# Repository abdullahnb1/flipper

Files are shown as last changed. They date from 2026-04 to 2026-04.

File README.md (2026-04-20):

# Final Engineering Design Project

Project Animation

## Project Overview
This repository contains the CAD assemblies and electronic specifications for the final design project of **ME461: Mechatronic Components and Instrumentation**. The system is designed with a focus on modularity and ease of assembly, utilizing standardized fasteners and common manufacturing techniques.

It is collaboratively maintained by:

- **Abdullah Naci Bodur**  
- **Ogan Altuğ Okutan**  
- **Buğra Çınaroğlu**

## Folder Structure
```
├── base/
│   ├── 3d/                     # 3d parts for base assembly
│   ├── BOM of base_assembly.csv
│   ├── BOM of base_electronic_assembly.csv
│   ├── BOM of base_rasppi_assembly.csv
│   ├── BOM of battery_base_assembly.csv
│   └── BOM of pico_base_assembly.csv
├── flipper/
│   ├── 3d/                     # 3d parts for flipper assembly
│   ├── plexy/                  # plexy parts for flipper assembly   
|   └── BOM of flipper_v2_assembly.csv       
└── media/                      # Assembly and manufacturing images
└── pc_client_code/             # MicroPython code for Pico W
```   

## Manufacturing Specifications
* **3D Printing:** Primary structural components are printed using **PLA**.
* **Laser Cutting:** Support plates and enclosures are manufactured from **Plexiglass**.
* **Fasteners:** For maintenance convenience and standardization, the entire assembly utilizes **M3 Hex Socket Screws** exclusively.

---

## CAD Design & Assembly

### 1. Robot Base
The primary chassis of the robot, housing the 18650 battery pack, 4S BMS, and power regulation systems. This section serves as the structural foundation for the entire assembly.

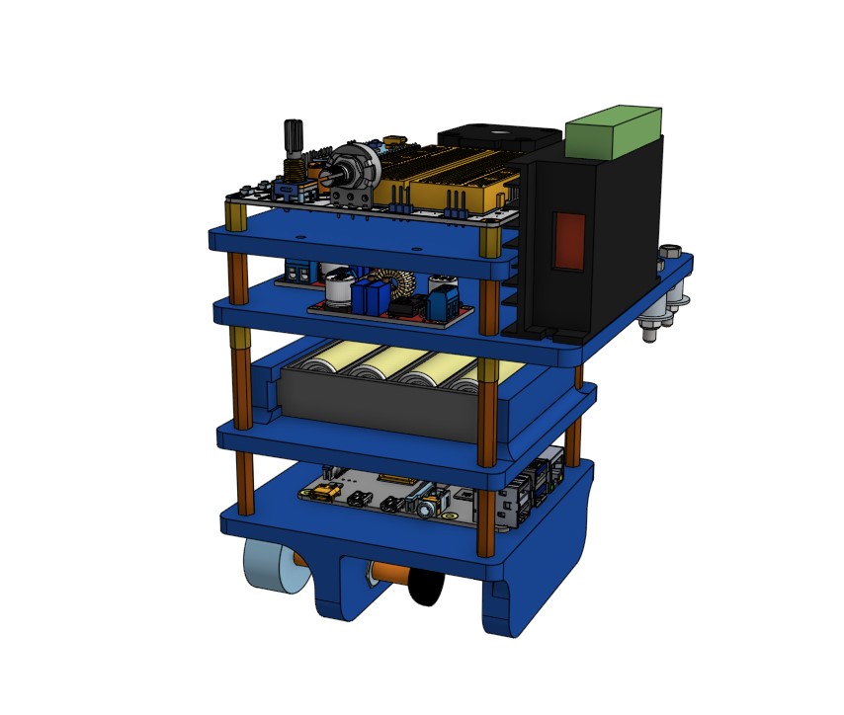
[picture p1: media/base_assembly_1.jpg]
Robot Base

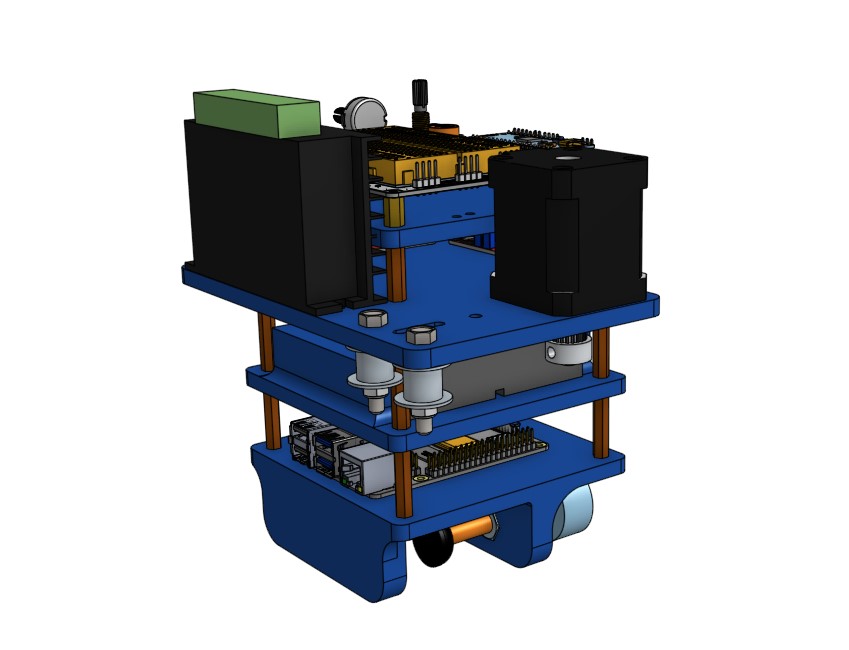
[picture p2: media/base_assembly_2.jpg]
Robot Base


### 2. Flipper Mechanism
The active actuation system of the robot. This folder contains the designs for the rolling carts mounts, the MG90S servo integration, and the mechanical linkages responsible for the flipping motion.

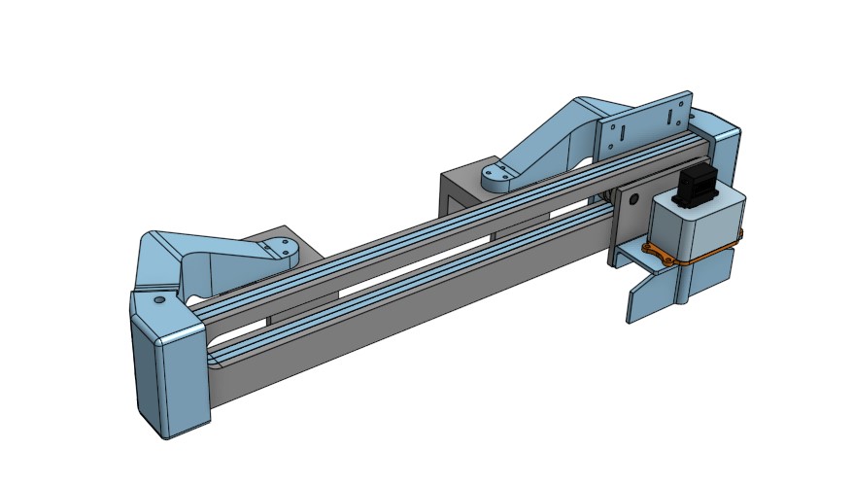
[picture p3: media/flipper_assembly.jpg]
Flipper Mechanism


### 3. Table Assembly
The stationary or receiving platform of the design. It incorporates the aluminum extruision parts that shows the game area, and a table that is inclined 5-8 degree relative to ground. Also 2 version of the **Flipper Robot** is shown; on the left v1 and on the right v2. Only the version 2 files added to the repository.

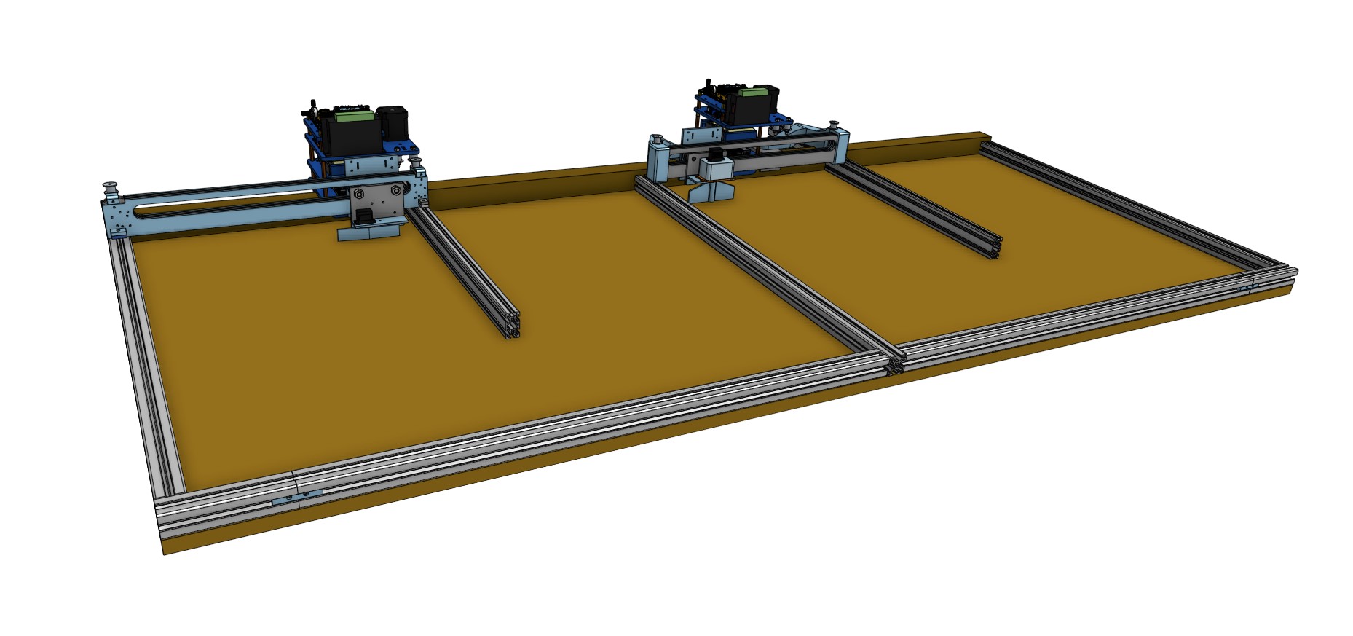
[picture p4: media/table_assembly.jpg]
Table Assembly


---

## Electronics
The system is powered by a high-discharge battery configuration and controlled via a Raspberry Pi Pico W architecture.

| Component | Quantity | Description |
| :--- | :--- | :--- |
| **Raspberry Pi Pico W** | 1 | Main microcontroller for logic and wireless connectivity. |
| **MechaBoard** | 1 | Integrated carrier board. [View on GitHub](https://github.com/rustemsevik/pico-Breadboard-Kit/tree/5a5b2b6fdedf8019d1d9c465f88ec24519eb11b5) |
| **18650 Li-ion Cells** | 4 | Primary power source (4S configuration). |
| **4S BMS** | 1 | Battery Management System for charging and protection. |
| **XL 4015** | 2 | Adjustable step-down voltage regulators for logic and motors. |
| **Nema17 Stepper** | 1 | High-torque motor for primary actuation. |
| **Microstepper Driver** | 1 | Controls the Nema17 with high microstepping resolution. |
| **MG90S Servo** | 1 | Metal-geared micro servo for auxiliary movement. |
| **Limit Switch** | 2 | Used for homing and physical end-stop detection. |

---

## Assembly Quick-Start
1.  **Fabrication:** Print PLA parts and laser cut Plexiglass components.
2.  **Hardware:** Gather M3 hex socket screws for all mechanical connections.
3.  **Electronics:** Mount the Pico W onto the MechaBoard and configure the XL 4015 regulators to the required voltages before connecting logic components.
4.  **Firmware:** Upload the control script to the Pico W.

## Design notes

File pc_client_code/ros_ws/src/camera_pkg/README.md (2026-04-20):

To run this package you first need to create a ROS2 Humble workspace.
- Copy this package into the src folder in your workspace
- Go to the root of your workspace and build the package with,
    colcon build --symlink-install --packages-select camera_pkg
- After you build the package you can start publishing camera frames with,
    ros2 run camera_pkg camera_publisher_node
- and receive those frames with
    ros2 run camera_pkg camera_subscriber_node

I wrote the commands from the top of my head, there might be some errors or typos.
Here is a usefull tutorial for ROS2 (if the link doesn't work, just search for the title in YouTube):
- [ROS2 Tutorials - ROS2 Humble For Beginners](https://youtube.com/playlist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)

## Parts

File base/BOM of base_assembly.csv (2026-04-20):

Item | Quantity | Name
1 | 1 | base_rasppi_assembly
2 | 1 | battery_base_assembly
3 | 1 | pico_base_assembly
4 | 1 | base_electronic_assembly

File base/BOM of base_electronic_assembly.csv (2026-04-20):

Item | Quantity | Name
1 | 1 | base_v2
2 | 2 | XL4015 Voltage regulator
3 | 4 | hex_m3_l20_bn
4 | 1 | Nema 17 Stepper Motor - 48mm - 1.8degree, 76oz-in v1
5 | 1 | GT2 20T 10mm
6 | 2 | 10mm Idle Pulley
7 | 2 | M5 Nylock Nut 1_90576A104
8 | 2 | hex screw_am(B18.6.7M - M5 x 0.8 x 30 Indented HHMS --30N)
9 | 1 | Microstep Driver

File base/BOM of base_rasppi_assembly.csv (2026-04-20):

Item | Quantity | Name
1 | 1 | base_v2
2 | 1 | PCB, RPi4ModelB
3 | 4 | hex_m3_l30_bn
4 | 2 | hex nut style 1 gradeab_iso_Hexagon Nut ISO - 4032 - M8 - W - N
5 | 2 | channel bolt M8x45mm
6 | 4 | hex socket m3x8mm
7 | 2 | knob
8 | 2 | damper

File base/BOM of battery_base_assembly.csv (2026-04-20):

Item | Quantity | Name
1 | 1 | base_v2
2 | 1 | battery_holder
3 | 4 | 18650_bpx8-2
4 | 4 | hex_m3_l30_bn
5 | 4 | hex_m3_l5_bn
6 | 4 | m3 hex nut

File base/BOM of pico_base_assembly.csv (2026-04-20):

Item | Quantity | Name
1 | 1 | base_v2
2 | 4 | Thread1
3 | 1 | pico-breadboard_PCB
4 | 1 | pico wh

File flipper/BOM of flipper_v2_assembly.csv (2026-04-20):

Item | Quantity | Name
1 | 2 | plexyglass_outside
2 | 2 | plexyglass_inside
3 | 1 | rolling_cart_1
4 | 1 | rolling_cart_2
5 | 1 | arm_1
6 | 1 | base_2
7 | 1 | base_1
8 | 1 | arm_2
9 | 4 | Bearing 608zz 8x22x7mm
10 | 2 | Hex Bolt M8x30 mm
11 | 1 | gearbox
12 | 1 | mg90s
13 | 1 | hex screw_am(B18.6.7M - M5 x 0.8 x 30 Indented HHMS --30N)
14 | 1 | M5 Hex Head Screw 20 mm
15 | 1 | M5 Nut
16 | 1 | mg90s_holder
17 | 1 | flipper_gearbox

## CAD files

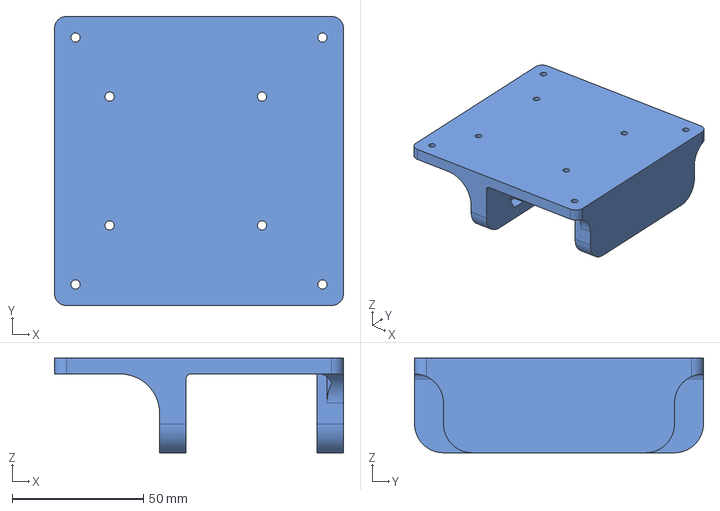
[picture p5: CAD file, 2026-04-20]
base/3d/base_rasppi.step
110.0 x 110.0 x 36.0 mm

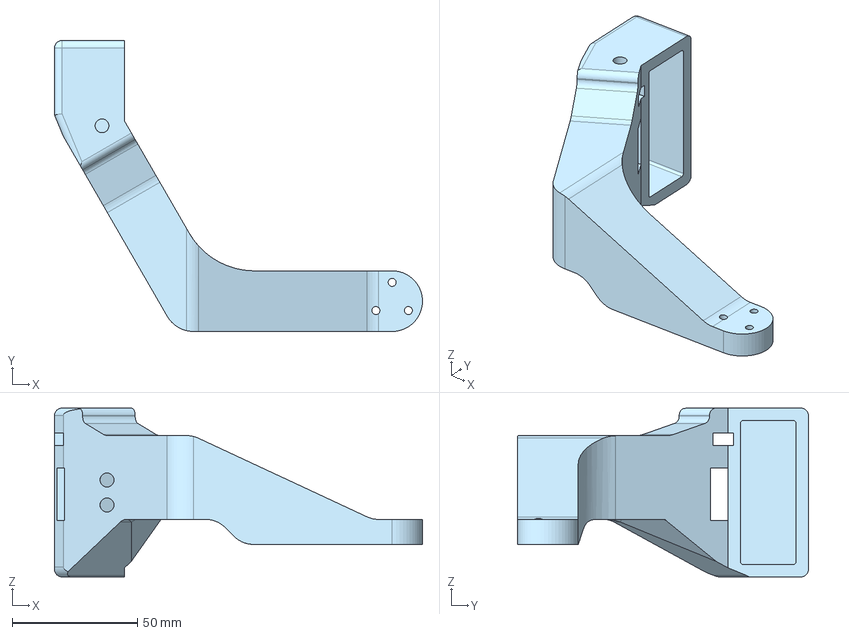
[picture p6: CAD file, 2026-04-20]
flipper/3d/flipper_base_connector_v2 - arm_1.step
147.1 x 116.3 x 67.5 mm

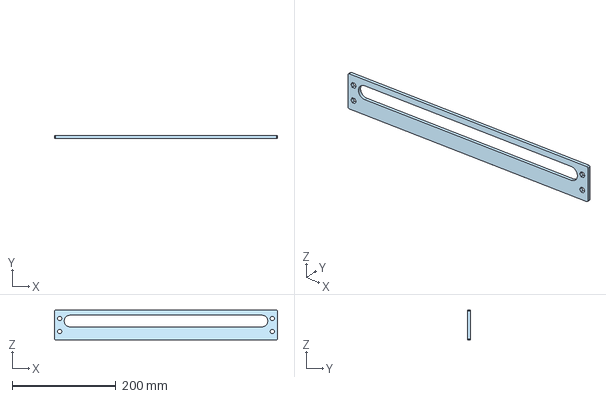
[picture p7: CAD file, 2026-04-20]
flipper/plexy/flipper_holder_v2_1 - plexyglass_inside.step
430.0 x 5.00 x 57.2 mm

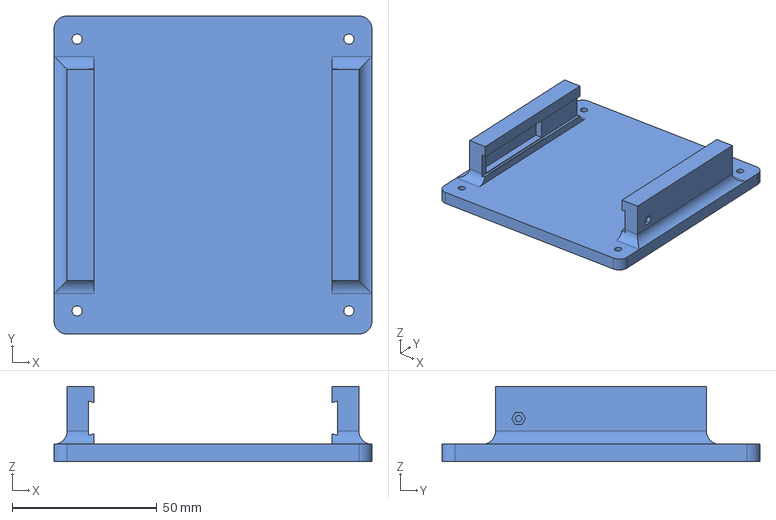
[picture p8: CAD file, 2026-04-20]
base/3d/base_battery_holder - base_v2.step
110.0 x 110.0 x 26.0 mm

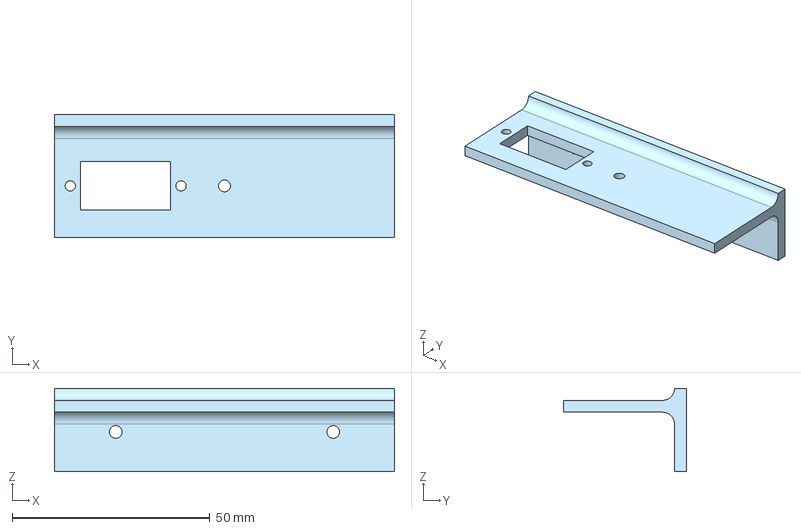
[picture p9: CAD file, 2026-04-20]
flipper/3d/mg90s_holder.step
86.0 x 31.0 x 21.0 mm

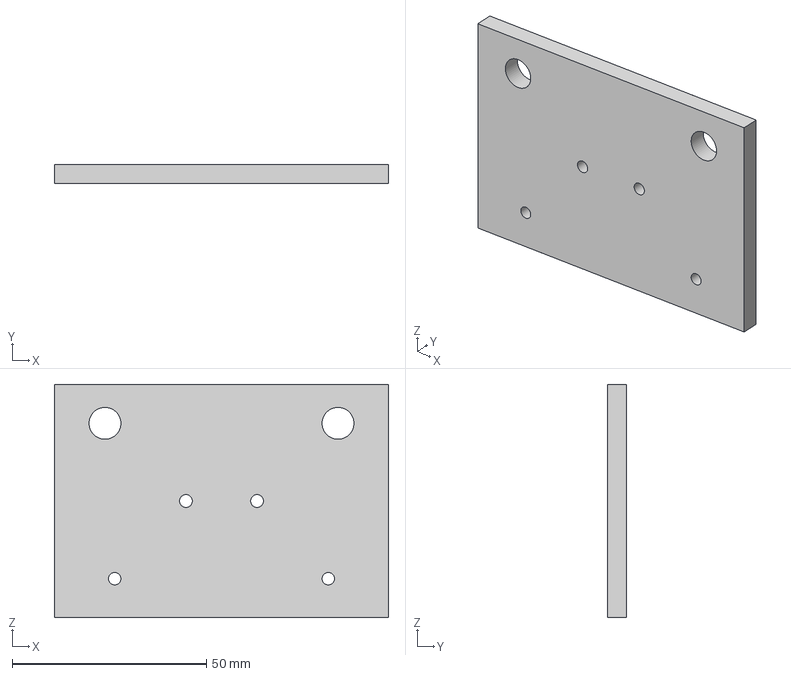
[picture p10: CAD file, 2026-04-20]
flipper/plexy/rolling_cart - rolling_cart_2.step
86.0 x 5.00 x 60.0 mm

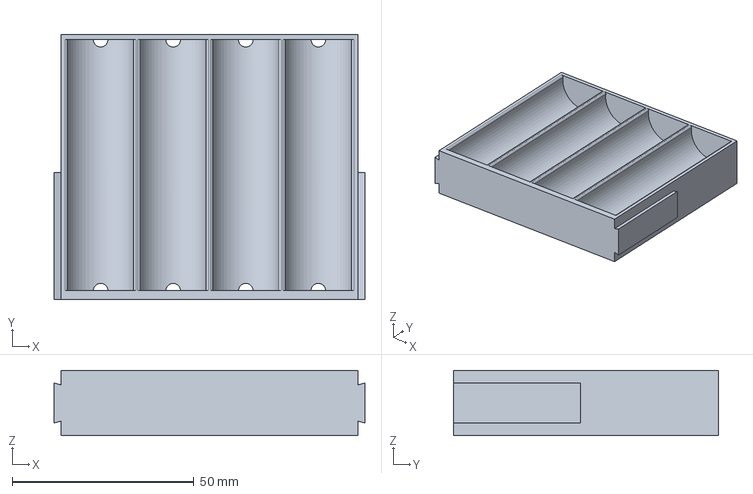
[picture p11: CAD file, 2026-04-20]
base/3d/battery_holder - battery_holder.step
85.5 x 73.0 x 18.0 mm

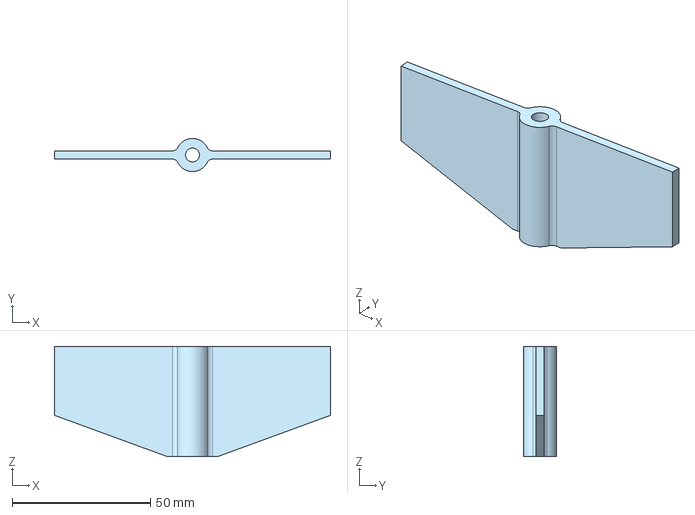
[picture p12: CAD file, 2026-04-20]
flipper/3d/flipper_gearbox - flipper_gearbox.step
100.0 x 12.0 x 40.0 mm

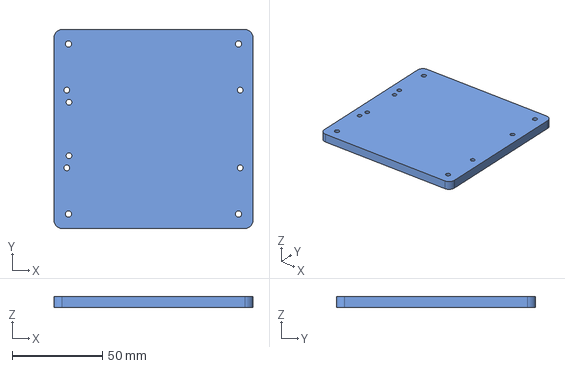
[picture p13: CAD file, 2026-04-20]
base/3d/base_v2.step
110.0 x 110.0 x 6.00 mm

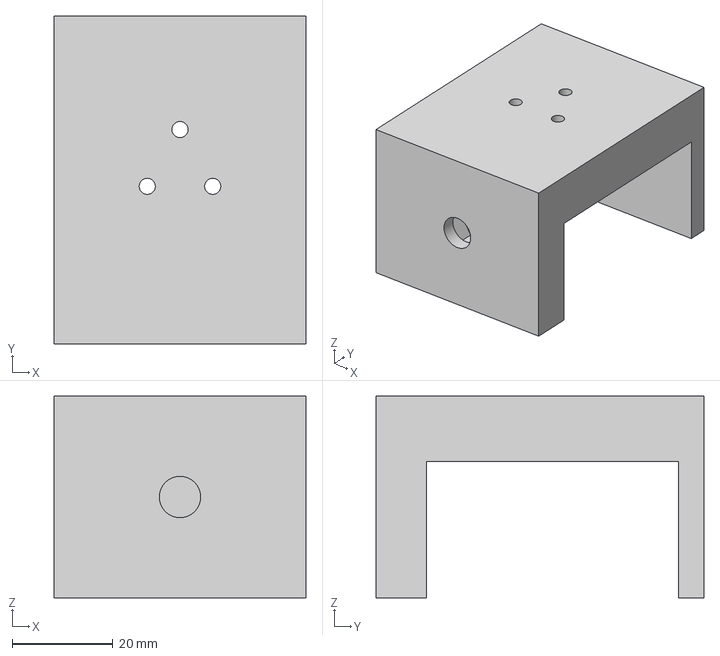
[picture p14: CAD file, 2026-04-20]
flipper/3d/flipper_base_connector_v2 - base_2.step
50.0 x 65.0 x 40.0 mm

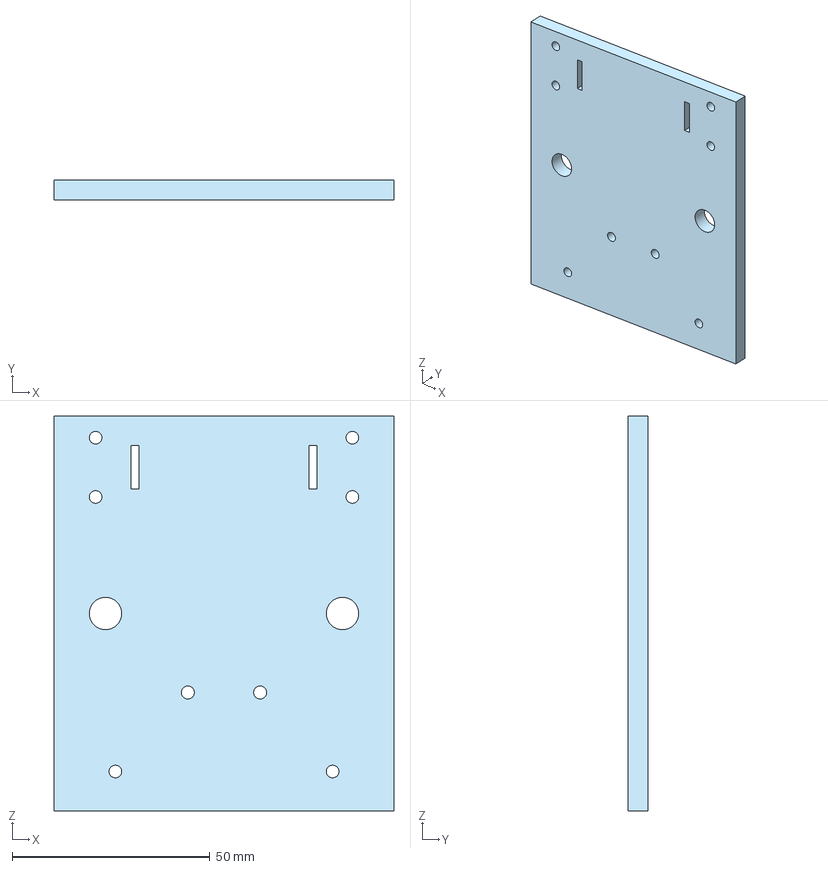
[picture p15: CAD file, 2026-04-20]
flipper/plexy/rolling_cart - rolling_cart_1.step
86.0 x 5.00 x 100.0 mm

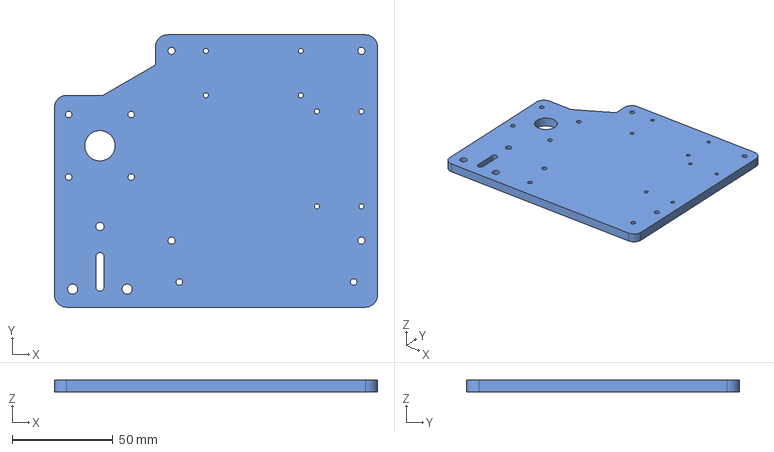
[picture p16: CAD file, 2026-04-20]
base/3d/base_electronics.step
160.0 x 135.0 x 6.00 mm

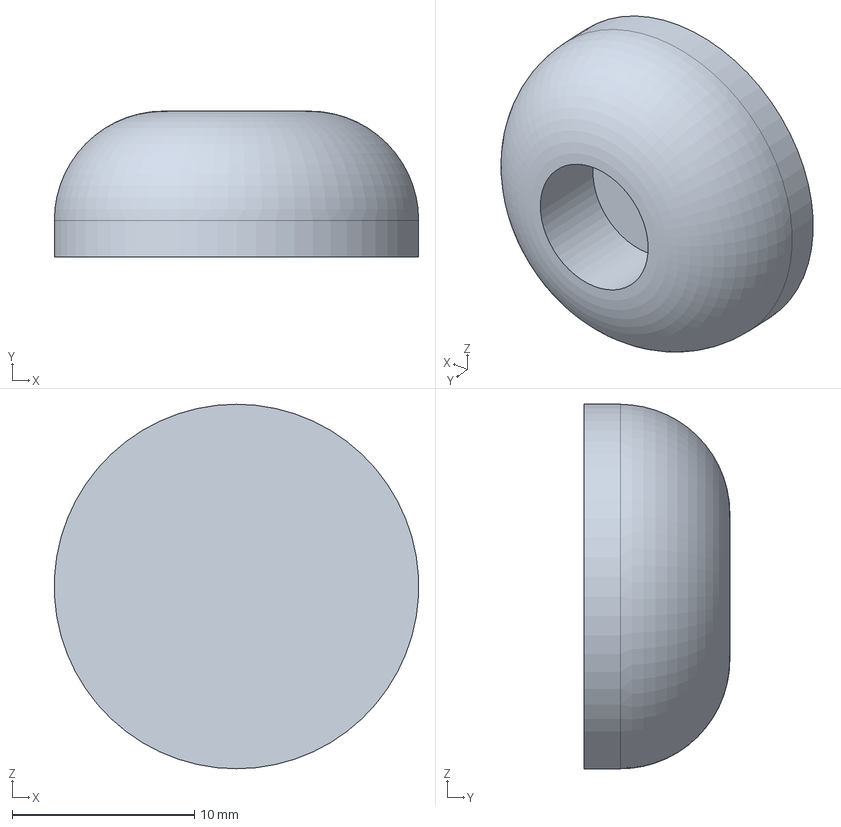
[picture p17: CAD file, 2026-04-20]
base/3d/damper - damper.step
20.0 x 8.00 x 20.0 mm

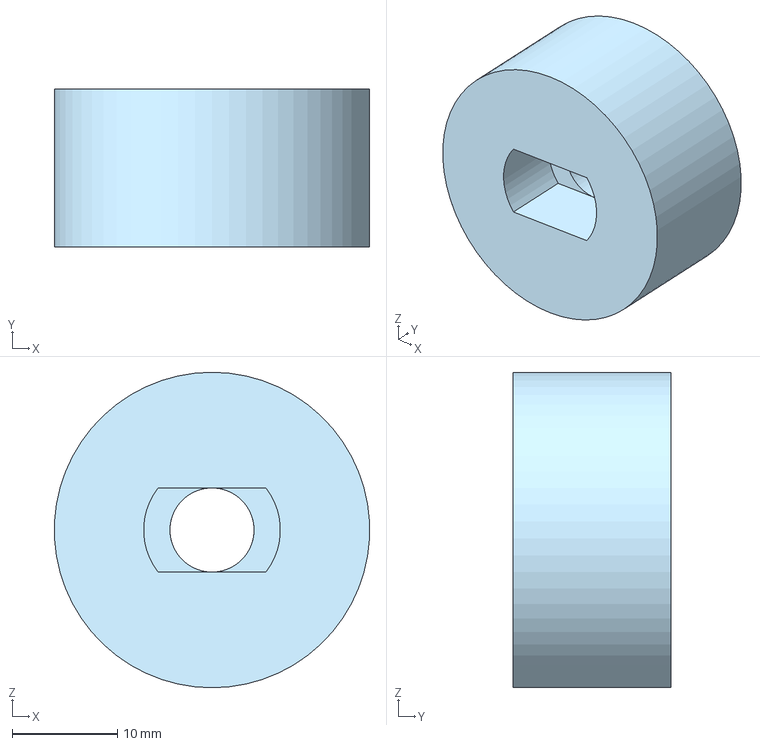
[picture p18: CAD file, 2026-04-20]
base/3d/knob.step
30.0 x 15.0 x 30.0 mm

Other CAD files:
flipper/plexy/flipper_holder_v2_1 - plexyglass_outside.step
flipper/3d/flipper_base_connector_v2 - base_1.step
flipper/3d/flipper_base_connector_v2 - arm_2.step

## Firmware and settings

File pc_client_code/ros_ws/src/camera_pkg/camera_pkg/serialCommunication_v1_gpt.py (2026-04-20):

# main.py — Pico / MicroPython
# Serial-command controller (USB CDC) for:
# - NEMA17 + TB6600 (STEP/DIR)
# - 2x limit switches (NC fail-safe recommended)
# - Two-way servo flipper (signed angles)
#
# PC sends commands like:
#   HOME
#   HOME 120 40 20000
#   GOTO 25.0
#   MOVE -5.0
#   SET_RPM 150
#   HIT +1 45 150
#   SERVO_GOTO -10
#   STATUS
#
# Pico replies as JSON lines, e.g.:
#   {"type":"ack","cmd":"HOME","ok":true}
#   {"type":"status","pos_mm":0.0,"pos_steps":0,"homed":true,"servo_signed_deg":0.0}

import machine
import time
import sys
import uselect

try:
    import ujson as json
except ImportError:
    import json

# =========================================================
# 1) LIMIT SWITCH
# =========================================================
class MicroSwitch:
    """
    For NC fail-safe wiring with PULL_UP:
      - Normal (not hit): pin reads 0 (connected to GND through NC contact)
      - Hit OR wire break: pin reads 1  => TRIGGERED
    """
    def __init__(self, pin_num, pull=machine.Pin.PULL_UP, triggered_level=1):
        self.pin = machine.Pin(pin_num, machine.Pin.IN, pull)
        self.triggered_level = 1 if int(triggered_level) else 0

    def raw_level(self) -> int:
        return int(self.pin.value())

    def is_triggered_raw(self) -> bool:
        return self.raw_level() == self.triggered_level


# =========================================================
# 2) SERVO (two-way flipper)
# =========================================================
class TwoWayServo:
    def __init__(self, pin_num, freq=50, min_us=500, max_us=2500,
                 abs_range_deg=180, center_angle=90, max_swing=60):
        self.pwm = machine.PWM(machine.Pin(pin_num))
        self.pwm.freq(int(freq))

        self.min_us = int(min_us)
        self.max_us = int(max_us)
        self.abs_range_deg = float(abs_range_deg)

        self.center_angle = float(center_angle)
        self.max_swing = float(max_swing)

        self.current_signed = 0.0
        self.goto_signed(0)

    def _abs_angle_to_duty_u16(self, abs_angle_deg: float) -> int:
        a = max(0.0, min(self.abs_range_deg, float(abs_angle_deg)))
        pulse_us = self.min_us + (a / self.abs_range_deg) * (self.max_us - self.min_us)
        period_us = 1_000_000 / self.pwm.freq()
        duty = int((pulse_us / period_us) * 65535)
        return max(0, min(65535, duty))

    def goto_abs(self, abs_angle_deg: float):
        self.pwm.duty_u16(self._abs_angle_to_duty_u16(abs_angle_deg))

    def goto_signed(self, signed_angle_deg: float):
        s = max(-self.max_swing, min(self.max_swing, float(signed_angle_deg)))
        self.current_signed = s
        self.goto_abs(self.center_angle + s)

    def hit(self, direction=+1, swing_deg=None, dwell_ms=120, return_ms=0):
        d = +1 if direction >= 0 else -1
        swing = self.max_swing if swing_deg is None else float(swing_deg)
        swing = max(0.0, min(self.max_swing, swing))

        self.goto_signed(d * swing)
        time.sleep_ms(int(dwell_ms))
        self.goto_signed(0)

        if return_ms > 0:
            time.sleep_ms(int(return_ms))


# =========================================================
# 3) STEPPER (TB6600) — TICKS-BASED TIMING (NO sleep_us in loops)
# =========================================================
class StepperBeltAxis:
    """
    Uses ticks_us scheduling to reduce timing jitter.
    No time.sleep_us() inside step loops (busy-wait scheduling instead).
    """
    def __init__(self,
                 step_pin, dir_pin,
                 rpm=60,
                 motor_steps_per_rev=200,
                 microstep=16,                 # match TB6600 DIP
                 belt_pitch_mm=2.0,
                 pulley_teeth=20,
                 left_switch=None, right_switch=None,
                 left_dir=0, right_dir=1,
                 backoff_mm=5.0,
                 step_high_us=5                # TB6600: 2–10us OK, 5us safe
                 ):
        self.step = machine.Pin(step_pin, machine.Pin.OUT)
        self.dir  = machine.Pin(dir_pin,  machine.Pin.OUT)

        self.motor_steps_per_rev = int(motor_steps_per_rev)
        self.microstep = int(microstep)

        self.belt_pitch_mm = float(belt_pitch_mm)
        self.pulley_teeth = int(pulley_teeth)

        self.mm_per_rev = self.belt_pitch_mm * self.pulley_teeth
        self.steps_per_rev = self.motor_steps_per_rev * self.microstep
        self.steps_per_mm = self.steps_per_rev / self.mm_per_rev

        self.step_high_us = int(step_high_us)

        self.sw_left  = left_switch
        self.sw_right = right_switch

        self.left_dir = int(left_dir) & 1
        self.right_dir = int(right_dir) & 1

        self.backoff_steps = max(1, int(round(float(backoff_mm) * self.steps_per_mm)))

        self.pos_steps = 0
        self.homed = False
        self.travel_steps = None
        self.left_limit_steps = None
        self.right_limit_steps = None

        self.set_rpm(rpm)
        self.step.value(0)

    # ---------- speed ----------
    def set_rpm(self, rpm, min_low_us=5):
        """
        Set axis speed in RPM with a safe minimum LOW time between pulses.

        min_low_us:
          Minimum time STEP stays LOW between pulses (in addition to step_high_us).
          5–10 us is a reasonable safety margin for TB6600 in MicroPython.
        """
        rpm = float(rpm)
        rpm = max(0.1, rpm)

        # Minimum allowed period (rising edge to rising edge)
        # Must be at least HIGH time + LOW time
        min_period_us = int(self.step_high_us + int(min_low_us))
        if min_period_us < self.step_high_us + 1:
            min_period_us = self.step_high_us + 1

        # Max steps/sec allowed by min period
        max_sps = 1_000_000.0 / float(min_period_us)

        # Convert that to max RPM for current steps_per_rev
        max_rpm_by_period = (max_sps * 60.0) / float(self.steps_per_rev)

        # Clamp RPM to achievable range
        # (If you want, you can also clamp to some global max like 800 here)
        rpm = min(rpm, max_rpm_by_period)
        self.rpm = rpm

        # Compute period from RPM
        sps = (self.rpm * self.steps_per_rev) / 60.0
        sps = max(1.0, sps)
        period_us = int(1_000_000 / sps)

        # Final safety clamp (should rarely trigger now)
        if period_us < min_period_us:
            period_us = min_period_us

        self.step_period_us = period_us


    # ---------- direction ----------
    def _set_dir(self, d):
        self.dir.value(1 if int(d) else 0)

    # ---------- position helpers ----------
    def pos_mm(self):
        return self.pos_steps / self.steps_per_mm

    def _clamp_target_steps(self, target_steps):
        if not self.homed or self.left_limit_steps is None or self.right_limit_steps is None:
            return target_steps
        return max(self.left_limit_steps, min(self.right_limit_steps, target_steps))

    # ---------- switch helpers ----------
    def _left_hit(self):
        return (self.sw_left is not None) and self.sw_left.is_triggered_raw()

    def _right_hit(self):
        return (self.sw_right is not None) and self.sw_right.is_triggered_raw()

    def _hit_in_direction(self, step_inc):
        if step_inc < 0 and self._left_hit():
            return True
        if step_inc > 0 and self._right_hit():
            return True
        return False

    # ---------- ticks helpers ----------
    def _busy_wait_until(self, t_us):
        while time.ticks_diff(t_us, time.ticks_us()) > 0:
            pass

    def _pulse_at(self, t_edge_us):
        self._busy_wait_until(t_edge_us)
        self.step.value(1)

        t_low = time.ticks_add(t_edge_us, self.step_high_us)
        self._busy_wait_until(t_low)
        self.step.value(0)

    # ---------- safety backoff ----------
    def _backoff_from_limit(self, step_inc):
        backoff_inc = +1 if step_inc < 0 else -1
        self._set_dir(self.right_dir if backoff_inc > 0 else self.left_dir)

        period = self.step_period_us
        next_edge = time.ticks_us()

        for _ in range(self.backoff_steps):
            if self._hit_in_direction(backoff_inc):
                break
            self._pulse_at(next_edge)
            self.pos_steps += backoff_inc
            next_edge = time.ticks_add(next_edge, period)

    # ---------- blocking motion (steps) ----------
    def move_steps(self, steps):
        steps = int(steps)
        if steps == 0:
            return True

        step_inc = +1 if steps > 0 else -1
        n = abs(steps)

        self._set_dir(self.right_dir if step_inc > 0 else self.left_dir)

        # clamp to homed limits
        if self.homed and self.left_limit_steps is not None and self.right_limit_steps is not None:
            final = self.pos_steps + step_inc * n
            final = self._clamp_target_steps(final)
            n = abs(final - self.pos_steps)
            if n == 0:
                return True
            step_inc = +1 if final > self.pos_steps else -1
            self._set_dir(self.right_dir if step_inc > 0 else self.left_dir)

        period = self.step_period_us
        next_edge = time.ticks_us()

        for _ in range(n):
            if self._hit_in_direction(step_inc):
                self._backoff_from_limit(step_inc)
                return False

            self._pulse_at(next_edge)
            self.pos_steps += step_inc
            next_edge = time.ticks_add(next_edge, period)

        return True

    # ---------- blocking motion (mm) ----------
    def move_mm(self, mm):
        target_steps = int(round(float(mm) * self.steps_per_mm))
        return self.move_steps(target_steps)

    def goto_mm(self, target_mm):
        target_steps = int(round(float(target_mm) * self.steps_per_mm))
        target_steps = self._clamp_target_steps(target_steps)
        return self.move_steps(target_steps - self.pos_steps)

    # =========================================================
    # HOMING
    # =========================================================
    def home(self, rpm_fast=120, rpm_slow=40, timeout_ms=20000):
        if self.sw_left is None or self.sw_right is None:
            raise RuntimeError("Need BOTH left and right switches for homing.")

        t0 = time.ticks_ms()
        def timed_out():
            return time.ticks_diff(time.ticks_ms(), t0) > int(timeout_ms)

        # release if starting on switch
        self.set_rpm(rpm_slow)
        period = self.step_period_us
        next_edge = time.ticks_us()

        if self._left_hit():
            self._set_dir(self.right_dir)
            while self._left_hit():
                if timed_out():
                    raise RuntimeError("Homing timeout while releasing LEFT.")
                self._pulse_at(next_edge)
                self.pos_steps += 1
                next_edge = time.ticks_add(next_edge, period)

        if self._right_hit():
            self._set_dir(self.left_dir)
            while self._right_hit():
                if timed_out():
                    raise RuntimeError("Homing timeout while releasing RIGHT.")
                self._pulse_at(next_edge)
                self.pos_steps -= 1
                next_edge = time.ticks_add(next_edge, period)

        # 1) seek left
        self.set_rpm(rpm_fast)
        period = self.step_period_us
        next_edge = time.ticks_us()
        self._set_dir(self.left_dir)

        while not self._left_hit():
            if timed_out():
                raise RuntimeError("Homing timeout seeking LEFT.")
            self._pulse_at(next_edge)
            self.pos_steps -= 1
            next_edge = time.ticks_add(next_edge, period)

        self._backoff_from_limit(step_inc=-1)
        self.pos_steps = 0

        # 2) seek right
        self.set_rpm(rpm_fast)
        period = self.step_period_us
        next_edge = time.ticks_us()
        self._set_dir(self.right_dir)

        while not self._right_hit():
            if timed_out():
                raise RuntimeError("Homing timeout seeking RIGHT.")
            self._pulse_at(next_edge)
            self.pos_steps += 1
            next_edge = time.ticks_add(next_edge, period)

        self.travel_steps = int(self.pos_steps)
        if self.travel_steps <= 0:
            raise RuntimeError("Homing failed: travel_steps <= 0 (swap left_dir/right_dir).")

        self._backoff_from_limit(step_inc=+1)

        # 3) go to center
        center_from_left = self.travel_steps // 2
        self.set_rpm(rpm_slow)
        self.move_steps(-(center_from_left))

        # define center as 0
        self.pos_steps = 0
        half = self.travel_steps // 2
        self.left_limit_steps = -half
        self.right_limit_steps = +half
        self.homed = True
        return True


# =========================================================
# 4) CONFIG
# =========================================================
PIN_STEP = 16
PIN_DIR  = 13

PIN_SERVO = 10

PIN_SW_LEFT  = 28
PIN_SW_RIGHT = 27

MICROSTEP = 2
INITIAL_RPM = 120

BELT_PITCH_MM = 2.0
PULLEY_TEETH = 20

LEFT_DIR  = 0
RIGHT_DIR = 1

BACKOFF_MM = 5.0


# =========================================================
# 5) SERIAL COMMS + COMMANDS
# =========================================================
BUSY = False

def send(obj):
    # Always send one JSON object per line
    try:
        sys.stdout.write(json.dumps(obj) + "\n")
    except Exception:
        # fallback minimal
        sys.stdout.write('{"type":"error","msg":"json_fail"}\n')

def status_payload(axis, servo):
    return {
        "type": "status",
        "pos_mm": float(axis.pos_mm()),
        "pos_steps": int(axis.pos_steps),
        "homed": bool(axis.homed),
        "servo_signed_deg": float(servo.current_signed),
        "busy": bool(BUSY),
    }

def ack(cmd, ok=True, **extra):
    out = {"type": "ack", "cmd": cmd, "ok": bool(ok)}
    for k, v in extra.items():
        out[k] = v
    send(out)

def err(cmd, msg, **extra):
    out = {"type": "error", "cmd": cmd, "msg": str(msg)}
    for k, v in extra.items():
        out[k] = v
    send(out)

def parse_line(line):
    # strip CRLF and split by whitespace
    line = line.strip()
    if not line:
        return None, []
    parts = line.split()
    cmd = parts[0].upper()
    args = parts[1:]
    return cmd, args

def to_float(s, default=None):
    try:
        return float(s)
    except:
        return default

def to_int(s, default=None):
    try:
        return int(s)
    except:
        return default

def handle_command(cmd, args, axis, servo):
    global BUSY

    # Always allow STATUS / PING even if busy
    if cmd in ("STATUS",):
        send(status_payload(axis, servo))
        return
    if cmd in ("PING",):
        ack("PING", ok=True)
        return
    if cmd in ("HELP", "?"):
        send({
            "type": "help",
            "commands": [
                "HOME [rpm_fast rpm_slow timeout_ms]",
                "GOTO <mm>",
                "MOVE <mm>",
                "SET_RPM <rpm>",
                "SERVO_GOTO <signed_deg>",
                "HIT <dir(+1/-1)> [swing_deg] [dwell_ms]",
                "STATUS",
                "PING",
            ]
        })
        return

    if BUSY:
        err(cmd, "busy")
        return

    # ---- Motion commands (blocking) ----
    if cmd == "HOME":
        rpm_fast = 120.0
        rpm_slow = 40.0
        timeout  = 20000

        if len(args) >= 1:
            v = to_float(args[0], None)
            if v is None: return err(cmd, "bad rpm_fast")
            rpm_fast = v
        if len(args) >= 2:
            v = to_float(args[1], None)
            if v is None: return err(cmd, "bad rpm_slow")
            rpm_slow = v
        if len(args) >= 3:
            v = to_int(args[2], None)
            if v is None: return err(cmd, "bad timeout_ms")
            timeout = v

        BUSY = True
        ack(cmd, ok=True, started=True)
        try:
            axis.home(rpm_fast=rpm_fast, rpm_slow=rpm_slow, timeout_ms=timeout)
            ack(cmd, ok=True, done=True)
            send(status_payload(axis, servo))
        except Exception as e:
            err(cmd, str(e))
        finally:
            BUSY = False
        return

    if cmd == "GOTO":
        if len(args) < 1:
            return err(cmd, "missing mm")
        mm = to_float(args[0], None)
        if mm is None:
            return err(cmd, "bad mm")

        BUSY = True
        ack(cmd, ok=True, started=True, target_mm=float(mm))
        try:
            ok = axis.goto_mm(mm)
            ack(cmd, ok=bool(ok), done=True)
            send(status_payload(axis, servo))
        except Exception as e:
            err(cmd, str(e))
        finally:
            BUSY = False
        return

    if cmd == "MOVE":
        if len(args) < 1:
            return err(cmd, "missing mm")
        mm = to_float(args[0], None)
        if mm is None:
            return err(cmd, "bad mm")

        BUSY = True
        ack(cmd, ok=True, started=True, delta_mm=float(mm))
        try:
            ok = axis.move_mm(mm)
            ack(cmd, ok=bool(ok), done=True)
            send(status_payload(axis, servo))
        except Exception as e:
            err(cmd, str(e))
        finally:
            BUSY = False
        return

    if cmd == "SET_RPM":
        if len(args) < 1:
            return err(cmd, "missing rpm")
        rpm = to_float(args[0], None)
        if rpm is None:
            return err(cmd, "bad rpm")
        axis.set_rpm(rpm)
        ack(cmd, ok=True, rpm=float(axis.rpm), step_period_us=int(axis.step_period_us))
        return

    # ---- Servo commands ----
    if cmd == "SERVO_GOTO":
        if len(args) < 1:
            return err(cmd, "missing signed_deg")
        deg = to_float(args[0], None)
        if deg is None:
            return err(cmd, "bad signed_deg")
        servo.goto_signed(deg)
        ack(cmd, ok=True)
        send(status_payload(axis, servo))
        return

    if cmd == "HIT":
        if len(args) < 1:
            return err(cmd, "missing dir")
        direction = to_int(args[0], None)
        if direction is None or direction == 0:
            return err(cmd, "bad dir (use +1 or -1)")

        swing = None
        dwell = 150

        if len(args) >= 2:
            swing = to_float(args[1], None)
            if swing is None:
                return err(cmd, "bad swing_deg")
        if len(args) >= 3:
            dwell = to_int(args[2], None)
            if dwell is None:
                return err(cmd, "bad dwell_ms")

        BUSY = True
        ack(cmd, ok=True, started=True)
        try:
            servo.hit(direction=direction, swing_deg=swing, dwell_ms=dwell)
            ack(cmd, ok=True, done=True)
            send(status_payload(axis, servo))
        except Exception as e:
            err(cmd, str(e))
        finally:
            BUSY = False
        return

    return err(cmd, "unknown_command")


def serial_loop(axis, servo):
    # Non-blocking line reader over USB serial (stdin)
    poll = uselect.poll()
    poll.register(sys.stdin, uselect.POLLIN)

    # announce ready
    send({"type": "ready", "msg": "pico_controller_ready"})
    send(status_payload(axis, servo))

    buf = ""

    while True:
        # poll with small timeout (ms)
        events = poll.poll(20)
        if not events:
            # optional: you can periodically stream status here if you want
            continue

        for _fd, ev in events:
            if ev & uselect.POLLIN:
                ch = sys.stdin.read(1)
                if not ch:
                    continue
                if ch == "\r":
                    continue
                if ch == "\n":
                    cmd, args = parse_line(buf)
                    buf = ""
                    if cmd is None:
                        continue
                    handle_command(cmd, args, axis, servo)
                else:
                    # prevent runaway buffer
                    if len(buf) < 200:
                        buf += ch
                    else:
                        buf = ""
                        err("RX", "line_too_long")


# =========================================================
# 6) BOOT
# =========================================================
if __name__ == "__main__":
    left_sw  = MicroSwitch(PIN_SW_LEFT,  pull=machine.Pin.PULL_UP, triggered_level=1)
    right_sw = MicroSwitch(PIN_SW_RIGHT, pull=machine.Pin.PULL_UP, triggered_level=1)

    servo = TwoWayServo(
        PIN_SERVO,
        center_angle=90,
        max_swing=60
    )
    servo.goto_signed(0)
    time.sleep_ms(200)

    axis = StepperBeltAxis(
        step_pin=PIN_STEP,
        dir_pin=PIN_DIR,
        rpm=INITIAL_RPM,
        microstep=MICROSTEP,
        belt_pitch_mm=BELT_PITCH_MM,
        pulley_teeth=PULLEY_TEETH,
        left_switch=left_sw,
        right_switch=right_sw,
        left_dir=LEFT_DIR,
        right_dir=RIGHT_DIR,
        backoff_mm=BACKOFF_MM,
        step_high_us=5
    )

    serial_loop(axis, servo)

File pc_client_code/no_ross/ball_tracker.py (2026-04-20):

import cv2
import numpy as np
import json
import os
import time
from collections import deque
from scipy.optimize import curve_fit

class BallTracker:
    def __init__(self, settings_file="hsv_settings.json", calibration_file="calibration_params.json"):
        # --- CONFIGURATION ---
        self.BUFFER_SIZE = 32
        self.MIN_RADIUS = 6
        self.MAX_DISTANCE = 50
        self.MAX_DISAPPEARED = 20
        self.WARMUP_FRAMES = 60
        self.TABLE_SLOPE_DEG = 3.5
        
        # --- VELOCITY FILTER CONFIG ---
        self.VEL_FILTER_SIZE = 2    
        self.VEL_DECAY_WEIGHT = 0.1  
        self.MAX_VELOCITY_MM_S = 500.0 
        
        # --- PATH RESOLUTION ---
        package_dir = os.path.dirname(os.path.abspath(__file__))
        self.SETTINGS_FILE = os.path.join(package_dir, settings_file)
        self.CALIBRATION_FILE = os.path.join(package_dir, calibration_file)

        print(f"[Tracker] Loading settings from: {self.SETTINGS_FILE}")
        print(f"[Tracker] Loading calibration from: {self.CALIBRATION_FILE}")

        # --- STATE VARIABLES ---
        self.trails = []       
        self.objects = {}      
        self.next_object_id = 0
        self.frame_count = 0
        self.prev_frame_time = 0
        self.current_fps = 30.0 
        
        self.vel_history = deque(maxlen=self.VEL_FILTER_SIZE)

        # Processing Tools
        self.fgbg = cv2.createBackgroundSubtractorMOG2(history=500, varThreshold=16, detectShadows=False)
        self.settings = self._load_settings()
        
        # ArUco Setup
        self.aruco_dict = cv2.aruco.getPredefinedDictionary(cv2.aruco.DICT_4X4_50)
        self.aruco_params = cv2.aruco.DetectorParameters()
        
        # Perspective / Physics State
        self.perspective_marker_id = -1
        self.marker_real_size = 0.0
        self.pixels_per_meter = 0 
        self.perspective_matrix = None
        self.warped_size = (640, 480) 
        
        # ROI & Goal Line State
        self.roi_marker_ids = None 
        self.roi_offsets = (0, 0)
        self.roi_goal_offset = 0   
        
        # CACHED STATE
        self.cached_roi_rects = None      
        self.cached_goal_line_y = None 
        self.cached_origin_px = None
        
        # Origin & Constraint State
        self.origin_marker_ids = None 
        self.origin_offset_mm = (0, 0)
        
        # Robot Physical Constraints (Asymmetric)
        self.robot_min_x_mm = -150.0 
        self.robot_max_x_mm = 150.0  
        self.robot_width_mm = 50.0   
        self.safe_margin_mm = 10.0   
        
        # VISUALIZATION EXTRAS
        self.flipper_boundary_x_mm = None 

        # Calibration State
        self.camera_matrix = None
        self.dist_coeffs = None
        self._load_calibration() 

        # Display State
        self.current_frame = None  
        self.current_mask = None
        self.raw_frame = None
        self.sliders_window_created = False

    # ------------------------------------------------------------------
    #   SETTINGS & CALIBRATION
    # ------------------------------------------------------------------
    def _load_settings(self):
        default = {"h_min": 0, "h_max": 30, "s_min": 100, "s_max": 255, "v_min": 100, "v_max": 255, "use_motion": 1}
        if os.path.exists(self.SETTINGS_FILE):
            try:
                with open(self.SETTINGS_FILE, 'r') as f: return json.load(f)
            except: pass
        return default

    def save_settings(self):
        try:
            with open(self.SETTINGS_FILE, 'w') as f: 
                json.dump(self.settings, f)
            print("[Tracker] Settings Saved Successfully.")
            return True
        except Exception as e:
            print(f"[Tracker] Save Error: {e}")
            return False
    
    def _load_calibration(self):
        if os.path.exists(self.CALIBRATION_FILE):
            try:
                with open(self.CALIBRATION_FILE, 'r') as f:
                    data = json.load(f)
                    
                    cm = data.get("camera_matrix")
                    if cm: self.camera_matrix = np.array(cm)
                    else: self.camera_matrix = None
                        
                    dc = data.get("dist_coeffs")
                    if dc: self.dist_coeffs = np.array(dc)
                    else: self.dist_coeffs = None

                    self.pixels_per_meter = data.get("pixels_per_meter", 0)
                    
                    pm = data.get("perspective_matrix")
                    if pm: self.perspective_matrix = np.array(pm)
                    
                    self.warped_size = tuple(data.get("warped_size", (1280, 720)))
                    self.perspective_marker_id = data.get("perspective_marker_id", -1)
                    self.marker_real_size = data.get("marker_real_size", 0.0)
            except Exception as e:
                print(f"[Tracker] Calibration Load Error: {e}")

    def _save_calibration(self):
        data = {
            "camera_matrix": self.camera_matrix.tolist() if self.camera_matrix is not None else [],
            "dist_coeffs": self.dist_coeffs.tolist() if self.dist_coeffs is not None else [],
            "pixels_per_meter": self.pixels_per_meter,
            "perspective_matrix": self.perspective_matrix.tolist() if self.perspective_matrix is not None else [],
            "warped_size": self.warped_size,
            "perspective_marker_id": self.perspective_marker_id,
            "marker_real_size": self.marker_real_size
        }
        with open(self.CALIBRATION_FILE, 'w') as f: json.dump(data, f)

    def calibrate_camera(self, cap_source, rows, cols, marker_id=None, marker_size_m=None, mode='both', rotation=0):
        print(f"--- CALIBRATION START ({mode}) ---")
        frame_for_scale = None
        
        # --- 1. DISTORTION ---
        if mode in ['both', 'distortion']:
            print("STEP 1: Lens Distortion. Using RAW FRAME (Ignore Rotation).")
            criteria = (cv2.TERM_CRITERIA_EPS + cv2.TERM_CRITERIA_MAX_ITER, 30, 0.001)
            objp = np.zeros((rows * cols, 3), np.float32)
            objp[:, :2] = np.mgrid[0:rows, 0:cols].T.reshape(-1, 2)
            objpoints, imgpoints = [], []
            captured_count = 0

            while True:
                ret, frame = cap_source.read()
                if not ret: break
                
                gray = cv2.cvtColor(frame, cv2.COLOR_BGR2GRAY)
                display = frame.copy()
                ret_corners, corners = cv2.findChessboardCorners(gray, (rows, cols), None)
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
